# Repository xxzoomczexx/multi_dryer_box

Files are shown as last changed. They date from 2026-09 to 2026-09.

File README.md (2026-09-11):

# 🛠️ Multi-Box Filament Dryer - Hardware & 4-Layer PCB Design

Hardwarový návrh plošného spoje (PCB) pro řídicí desku sušičky filamentu s mikrokontrolérem **Raspberry Pi RP2350A** a Wi-Fi modulem **Raspberry Pi RM2**.

---

## 🎛️ 4-Vrstvý PCB Stackup (Maturitní Standard)

Návrh využívá **4vrstvou desku plošných spojů (4-Layer PCB)** pro zajištění vynikající elektromagnetické kompatibility (EMC), nízkého šumu pro 24-bitový ADC převodník váhy HX711 a stabilního chodu Wi-Fi modulu.

| Vrstva | Název v KiCad | Typ | Popis / Využití |
| :--- | :--- | :--- | :--- |
| **L1 (Top)** | `F.Cu` | **Signal** | Hlavní signálové vodiče (I2C, HX711, SWD, SPI pro Flash a RM2, spínání MOSFETu). |
| **L2 (Inner 1)** | `In1.Cu` | **GND Plane** | **Plná souvislá zemní plocha (GND)** pod všemi čipy, napájecím zdrojem i RF částí. |
| **L3 (Inner 2)** | `In2.Cu` | **Power Plane** | Rozlitá napájecí zóna (**+3.3V** a rozvod **+5V / +12V** pro topná tělesa). |
| **L4 (Bottom)**| `B.Cu` | **Signal / GND**| Propojovací signálové vodiče a spodní stínění zemí. |

---

## 🧩 Hlavní Hardwarové Bloky (Hierarchická Schémata)

- ⚡ **`pwr.kicad_sch` (Napájecí zdroj):** Spínaný DC-DC buck měnič **AP63203WU** (vstup 3.8 V až 32 V přes jack `PJ-102AH`, výstup **+3.3 V / 2 A** pro RP2350, Flash i RM2).
- 📡 **`RM2.kicad_sch` (Wi-Fi / BT modul):** Modul **Raspberry Pi RM2** (čip CYW43439) připojený přes rozhraní SPI.
- 💾 **`flash.kicad_sch` (Flash paměť):** 16 MB QSPI Flash paměť **W25Q128JVS** pro uložení firmwaru.
- 🔌 **`susicka_filamentu.kicad_sch` (Mikrokontrolér a konektory):**
  - **Čip:** RP2350A (QFN-60).
  - **Programování:** **SWD Konektor** (`J2` - 3-pin / 4-pin Header: `SWCLK`, `SWDIO`, `GND`, `+3V3`). *(USB větev je vynechána - DNP)*.
  - **I2C Senzor teploty a vlhkosti:** Rozhraní pro senzor SHT40 (`SDA`, `SCL` s 4.7kΩ pull-up rezistory).
  - **Tenzometr váhy (HX711):** 4-pin konektor pro HX711 (`VCC`, `SCK`, `DT`, `GND`).
  - **MOSFET Spínač topení:** N-kanálový MOSFET (**AO3400A** / **IRLML6344TRPBF** v pouzdře SOT-23) s 10kΩ pulldown rezistorem na gate a ochrannou flyback diodou.

---

## 📏 Návod pro Layout a DRC v KiCad

1. **Keepout zóna pro Wi-Fi anténu:** Pod anténní částí modulu RM2 odstraňte měděné zóny ze všech 4 vrstev pro zachování plného dosahu Wi-Fi.
2. **GND Vrstva (In1.Cu):** Narušovat souvislou zemní plochu L2 co nejméně. Všechny piny GND připojovat krátkými prokovy (vias) přímo na L2.
3. **Filtrační kondenzátory:** Blokovací kondenzátory 100 nF a 10 µF umístit těsně k napájecím pinům RP2350A, W25Q128, AP63203 i RM2.

---

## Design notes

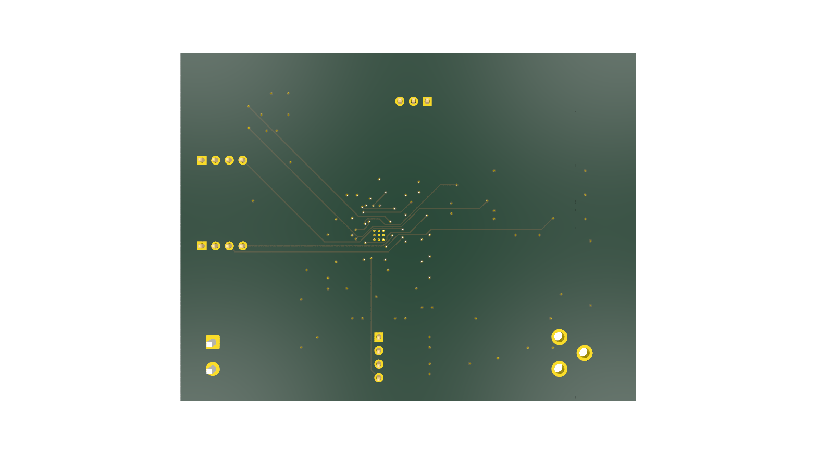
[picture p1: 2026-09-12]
pcb_bottom_render.png

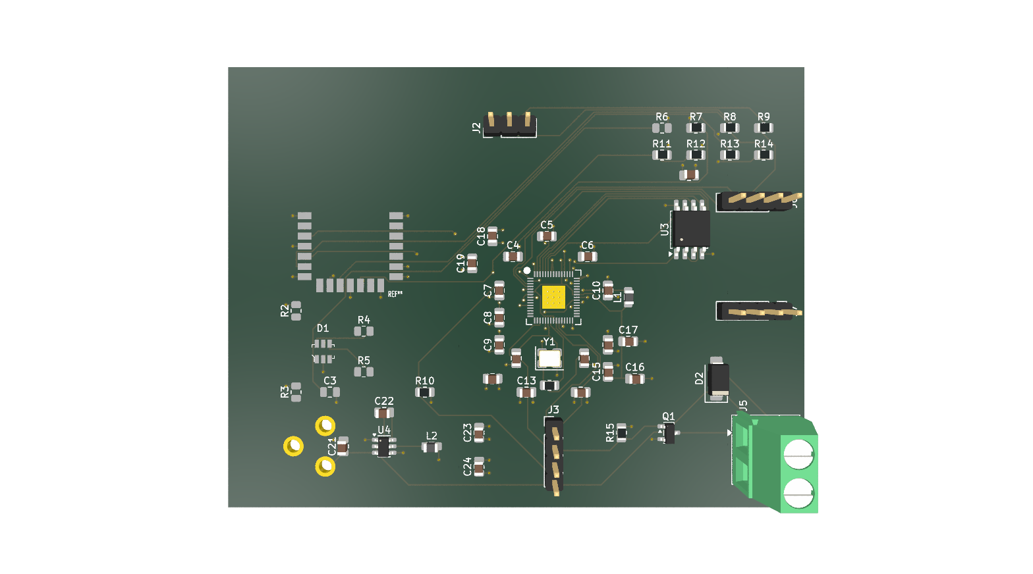
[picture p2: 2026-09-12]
pcb_top_render.png

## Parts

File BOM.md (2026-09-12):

# Kusovník součástek (Bill of Materials – BOM)
**Projekt:** IoT Sušička filamentu (*Maturitní práce*)  
**Deska:** 4vrstvá DPS (85 × 65 mm)  
**Datum:** 12. 9. 2026  

Tento kusovník obsahuje kompletní seznam všech součástek osazených na desce plošných spojů, včetně přesných katalogových čísel a odkazů z tabulky `C:\Users\mirac\Desktop\soucastky.xlsx`.

---

## 1. Souhrnná nákupní tabulka (Sdruženo podle typu součástky)

| Označení | Hodnota / Typ | Pouzdro | Počet | Reference na desce | Výrobce / Objednací kód | Odkaz na nákup |
| :--- | :--- | :--- | :---: | :--- | :--- | :--- |
| **U1** | **RP2350A** (MCU Dual ARM/RISC-V) | QFN-60 (7×7 mm, pitch 0,4 mm) | 1 ks | `U1` | Raspberry Pi `RP2350A0A4` | [TME](https://www.tme.eu/cz/details/sc1509-a4/raspberry-pi-vestavene-systemy/raspberry-pi/raspberry-pi-rp2350a0a4-7-reel/) |
| **U2** | **RM2** (Wi-Fi 4 / BLE 5.2 modul) | LGA / Castellated | 1 ks | `U2` | Raspberry Pi `RPI-RMC20452T` | [RPiShop](https://rpishop.cz/602192/raspberry-pi-radio-module-rmc20452t/) |
| **U3** | **W25Q128JVS** (128 Mbit QSPI Flash) | SOIC-8 (208 mil, 5,3×5,3 mm) | 1 ks | `U3` | Winbond `W25Q128JVSIQ-TR` | [Mouser](https://cz.mouser.com/ProductDetail/Winbond/W25Q128JVSIQ-TR?qs=qSfuJ%252Bfl%2Fd7vTyLA9kNdGw%3D%3D) |
| **U4** | **AP63203WU-7** (Step-down 24V $\to$ 3,3V 2A) | TSOT-23-6 | 1 ks | `U4` | Diodes Inc `AP63203WU-7` | [Mouser](https://cz.mouser.com/ProductDetail/Diodes-Incorporated/AP63203WU-7?qs=u16ybLDytRZ1JqxbuLkMJw%3D%3D) |
| **Y1** | **ABM8-272-T3** (Krystal 12.000 MHz) | SMD 3225-4Pin (3,2×2,5 mm) | 1 ks | `Y1` | Abracon `ABM8-272-T3` | [TME](https://www.tme.eu/cz/details/abm8-272-t3/resonators-and-generators/abracon/) |
| **L1** | **3,3 $\mu$H** (Power Inductor, VREG Core) | SMD 2016 / 0805 | 1 ks | `L1` | Abracon `AOTA-B201610S3R3-101-T` | [TME](https://www.tme.eu/cz/details/aota-b201610s3r3-1/tlumivky/abracon/aota-b201610s3r3-101-t/) |
| **L2** | **3,9 $\mu$H** (Power Inductor, Buck 3.3V) | SMD 2016 / 0805 | 1 ks | `L2` | Würth / Bourns (proud $\ge 2\text{ A}$) | Běžný SMD induktor |
| **Q1** | **N-MOSFET** (Spínač topení, 30V $\ge 5\text{A}$) | SOT-23 | 1 ks | `Q1` | např. `AO3400A` nebo `Si2302DS` | Běžný N-FET logická úroveň |
| **D1** | **USBLC6-2SC6** (ESD ochrana USB) | SOT-23-6 | 1 ks | `D1` | STMicroelectronics `USBLC6-2SC6` | TME / Mouser |
| **D2** | **SS14** (Schottky dioda 40V 1A) | SMA (DO-214AC) | 1 ks | `D2` | Běžná Schottky dioda `SS14` | TME / Mouser |
| **J4** | **PJ-102AH** (DC Jack 2,1×5,5 mm, 5A) | THT | 1 ks | `J4` | Same Sky (CUI) `PJ-102AH` | [Mouser](https://cz.mouser.com/ProductDetail/Same-Sky/PJ-102AH?qs=WyjlAZoYn50Yq4CrVLCXLw%3D%3D) |
| **J5** | **MKDS 1,5/ 2-5,00** (Šroubová svorkovnice 2p) | THT, rozteč 5,00 mm | 1 ks | `J5` | Phoenix Contact `1715721` | TME / Mouser |
| **J2** | **PinHeader 1×03** (Rozteč 2,54 mm) | THT Vertical | 1 ks | `J2` | Lámací kolíková lišta 2,54 mm | Běžná lišta |
| **J3, J6, J7** | **PinHeader 1×04** (Rozteč 2,54 mm / JST-XH) | THT Vertical | 3 ks | `J3, J6, J7` | Lámací kolíková lišta / JST-XH | Běžná lišta |

---

## 2. Pasivní součástky (Kondenzátory SMD 0805)

| Hodnota | Dielektrikum / Napětí | Počet | Označení na desce | Funkce v zapojení |
| :--- | :--- | :---: | :--- | :--- |
| **15 pF** | C0G/NP0, 50V | 2 ks | `C1, C2` | Zátěžové kondenzátory 12MHz krystalu Y1 |
| **4,7 nF** | X7R, 50V | 1 ks | `C3` | Vysokofrekvenční filtr na vstupu napájení USB |
| **100 nF** ($0{,}1\,\mu\text{F}$) | X7R, 25V / 50V | 13 ks | `C7, C8, C9, C10, C11, C12, C13, C14, C15, C17, C18, C20, C22` | Blokování VDD/IO pinů MCU, Flashky, RM2 a Bootstrap pro U4 |
| **4,7 $\mu$F** | X5R/X7R, 10V / 16V | 4 ks | `C4, C5, C6, C16` | Filtrace VREG_AVDD, Core 1.1V a lokální zásoba 3.3V |
| **10 $\mu$F** | X5R/X7R, 35V / 50V | 2 ks | `C19, C21` | Vstupní filtrace 24V u měniče U4 (`C21`) a filtrace RM2 (`C19`) |
| **22 $\mu$F** | X5R/X7R, 10V / 16V | 2 ks | `C23, C24` | Výstupní filtrace 3,3V měniče AP63203 |

*Celkem kondenzátorů:* **24 ks** (všechny v pouzdru SMD 0805 / 2012Metric).

---

## 3. Pasivní součástky (Rezistory SMD 0805)

| Hodnota | Tolerance | Počet | Označení na desce | Funkce v zapojení |
| :--- | :--- | :---: | :--- | :--- |
| **27 $\Omega$** | 1 %, 0805 | 2 ks | `R4, R5` | Sériové zakončení diferenciálních linek USB D+ / D- |
| **33 $\Omega$** | 1 %, 0805 | 1 ks | `R7` | Filtrační odpor pro interní lineární regulátor (VREG_AVDD) |
| **220 $\Omega$** | 1 %, 0805 | 2 ks | `R8, R9` | Sériové tlumicí rezistory pro SPI signály modulu RM2 |
| **470 $\Omega$** | 1 %, 0805 | 1 ks | `R14` | Tlumení datové linky modulu RM2 |
| **1 k$\Omega$** | 1 %, 0805 | 1 ks | `R1` | Sériový tlumicí rezistor oscilátoru Y1 (XOUT) |
| **5,1 k$\Omega$** | 1 %, 0805 | 2 ks | `R2, R3` | Konfigurační pull-down rezistory USB-C (CC1 / CC2) |
| **10 k$\Omega$** | 1 %, 0805 | 4 ks | `R10, R11, R12, R13` | Pull-up pro RUN/Reset tlačítko a řídicí linky RM2 |
| **100 k$\Omega$** | 5 %, 0805 | 1 ks | `R15` | Pull-down Gate rezistor pro MOSFET topení Q1 |
| **1 M$\Omega$** | 5 %, 0805 | 1 ks | `R6` | Paralelní zpětnovazební rezistor krystalu Y1 |

*Celkem rezistorů:* **15 ks** (všechny v pouzdru SMD 0805 / 2012Metric).

---

## 4. Doporučení pro nákup

1. **Pasiva (odpory a kondenzátory):**
   * Všechny pasivní součástky jsou zvoleny v pouzdru **0805 (2012 metric)**, což je ideální kompromis – snadno se pájí ručně mikropájkou i pastou, nejsou miniaturní jako 0402 a jsou extrémně levné (stojí jednotky haléřů za kus).
   * Doporučuji koupit rovnou vzorkovou knížečku (SMD sample book 0805) na AliExpressu nebo LaskaKitu, kde máš všechny hodnoty pohromadě.
2. **Klíčové čipy (U1, U2, U3, U4):**
   * Čipy RP2350A, W25Q128 a AP63203 objednej z Mouseru nebo TME podle přímých odkazů z tabulky.
   * Modul RM2 má skladem český RPiShop.cz.

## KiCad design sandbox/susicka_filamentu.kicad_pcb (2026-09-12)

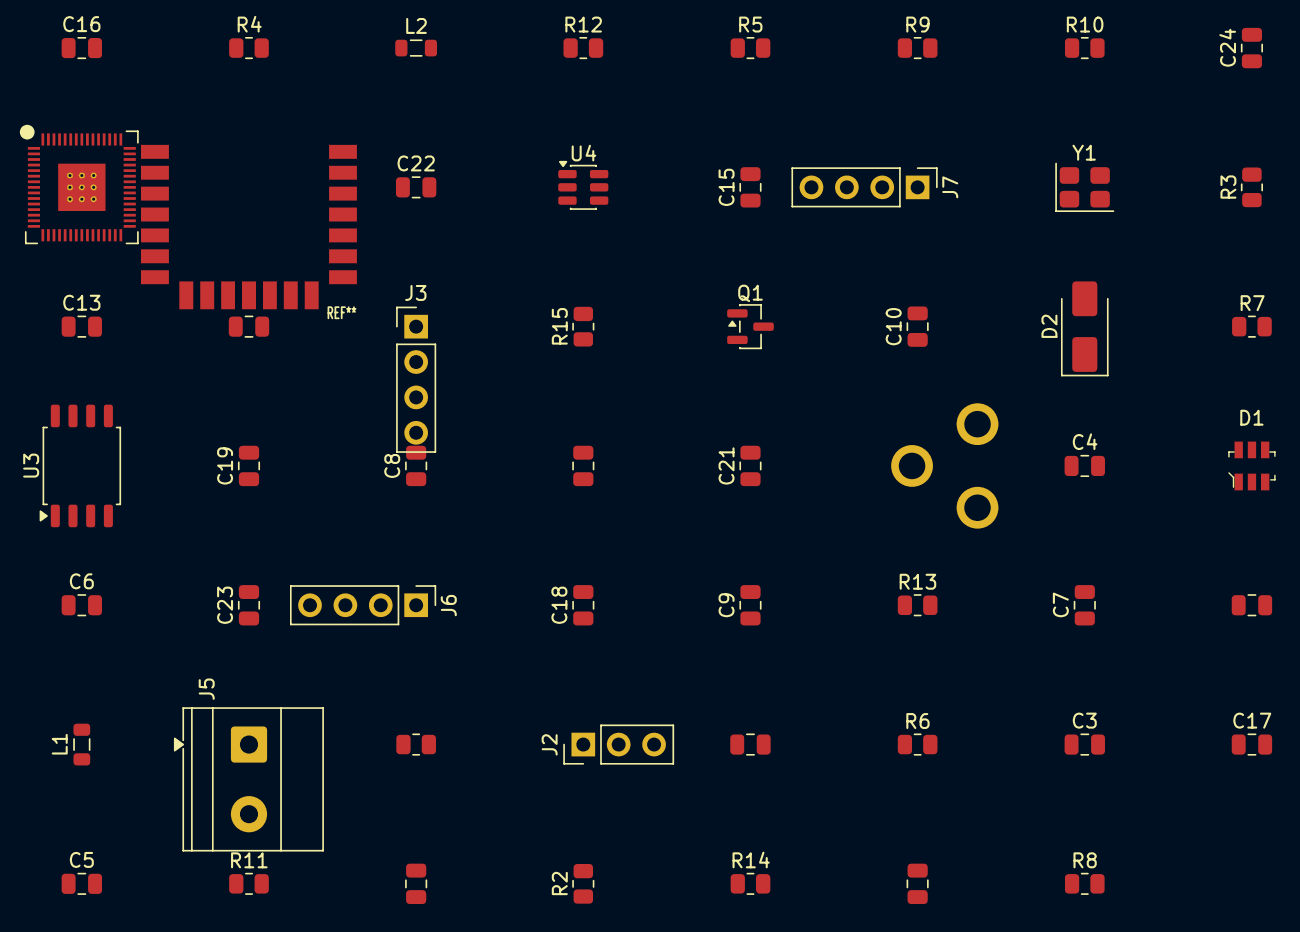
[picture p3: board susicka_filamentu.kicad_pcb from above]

Board: 4 copper layers, 55 parts (0 on the bottom side), 39 nets, no tracks yet.

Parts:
C1, C2: 15p; C_0805_2012Metric
C3: 4,7n; C_0805_2012Metric
C4: 4,7uF; C_0805_2012Metric
C5, C6, C16: 4,7 uF; C_0805_2012Metric
C7, C8, C9, C10, C11, C12, C13, C14, C15, C17, C18, C20, C22: 100 nF; C_0805_2012Metric
C19, C21: 10 uF; C_0805_2012Metric
C23, C24: 22 uF; C_0805_2012Metric
D1: USBLC6-2SC6; SOT23-6L
D2: SS14; D_SMA
J2: Conn_01x03; PinHeader_1x03_P2.54mm_Vertical
J3, J6, J7: Conn_01x04; PinHeader_1x04_P2.54mm_Vertical
J4: PJ-102AH
J5: Screw_Terminal_01x02; TerminalBlock_Phoenix_MKDS-1,5-2_1x02_P5.00mm_Horizontal
L1: AOTA-B201610S3R3-101-T; L_0805_2012Metric
L2: 3,9 uH; L_0805_2012Metric
Q1: Q_NMOS_GSD; SOT-23
R1: 1k; R_0805_2012Metric
R2, R3: 5,1k; R_0805_2012Metric
R4, R5: 27; R_0805_2012Metric
R6: 1M; R_0805_2012Metric
R7: 33; R_0805_2012Metric
R8, R9: 220; R_0805_2012Metric
R10, R11, R12, R13: 10k; R_0805_2012Metric
R14: 470; R_0805_2012Metric
R15: R; R_0805_2012Metric
U1: RP2350A-QFN60; RP2350A_QFN-60_EP_7.75x7.75_Pitch0.4mm
U2: RM2; rpi_rmc20452t
U3: W25Q128JVS; SOIC-8_5.3x5.3mm_P1.27mm
U4: AP63203WU; TSOT-23-6
Y1: Crystal_GND24; Crystal_SMD_3225-4Pin_3.2x2.5mm

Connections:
24V: C21.1, D2.1, J4.1, J5.1, U4.2 (EN), U4.3 (IN)
+1V1: C5.1, C15.1, C16.1, C17.1, L1.1, U1.6 (DVDD), U1.23 (DVDD), U1.39 (DVDD), U1.50 (VREG_FB)
+3V3: C6.1, C8.1, C9.1, C10.1, C11.1, C12.1, C13.1, C14.1, C18.1, C19.1, C20.1, C23.1, C24.1, J6.1, L2.2, R7.1, R10.2, U1.1 (IOVDD), U1.11 (IOVDD), U1.20 (IOVDD), U1.30 (IOVDD), U1.38 (IOVDD), U1.44 (ADC_AVDD), U1.45 (IOVDD), U1.49 (VREG_VIN), U1.53 (USB_OTP_VDD), U1.54 (QSPI_IOVDD), U2.14 (VDDIO), U2.16 (VIN), U3.8 (VCC), U4.1 (FB)
/GPIO14: Q1.1 (G), R15.1, U1.18 (GPIO14)
/RM2/RM2_BT_ON: R11.1, R12.1, U1.35 (GPIO23), U2.12 (WL_ON), U2.13 (BT_ON)
/RM2/RM2_CS: U1.37 (GPIO25), U2.9 (CS)
/RM2/RM2_DI: R13.1, R14.1, U1.36 (GPIO24), U2.5 (DI)
/RM2/RM2_SCLK: U1.43 (GPIO29_ADC3), U2.3 (SCLK)
/flash/QSPI_SCLK: U1.56 (QSPI_SCLK), U3.6 (CLK)
/flash/QSPI_SD0: U1.57 (QSPI_SD0), U3.5 (DI/IO_{0})
/flash/QSPI_SD1: U1.59 (QSPI_SD1), U3.2 (DO/IO_{1})
/flash/QSPI_SD2: U1.58 (QSPI_SD2), U3.3 (~WP/IO_{2})
/flash/QSPI_SD3: U1.55 (QSPI_SD3), U3.7 (~HOLD/~RESET/IO_{3})
/flash/QSPI_SS: U1.60 (QSPI_SS), U3.1 (~CS)
/oscillator/XIN: C1.2, U1.21 (XIN), Y1.3
/oscillator/XOUT: R1.2, U1.22 (XOUT)
DM: D1.4, R5.2
DP: D1.6, R4.2
GND: C1.1, C2.1, C3.2, C4.2, C5.2, C6.2, C7.1, C8.2, C9.2, C10.2, C11.2, C12.2, C13.2, C14.2, C15.2, C16.2, C17.2, C18.2, C19.2, C20.2, C21.2, C23.2, C24.2, D1.2, J2.3, J3.3, J4.2, J4.3, J6.2, J7.1, Q1.2 (S), R2.2, R3.2, R6.2, R11.2, R12.2, R15.2, U1.47 (VREG_PGND), U1.61 (GND), U2.1 (GND), U2.4 (GND), U2.7 (GND), U2.11 (GND), U2.15 (GND), U2.21 (GND), U3.4 (GND), U4.4 (GND), Y1.2, Y1.4
unnamed: C2.2, R1.1, Y1.1
unnamed: C3.1, R6.1
unnamed: J2.1, R8.2
unnamed: J2.2, R9.2
unnamed: C7.2, J3.4, R10.1, U1.26 (RUN)
unnamed: D2.2, J5.2, Q1.3 (D)
unnamed: J6.3, U1.4 (GPIO2)
unnamed: J6.4, U1.5 (GPIO3)
unnamed: J7.3, U1.7 (GPIO4)
unnamed: J7.4, U1.8 (GPIO5)
unnamed: R8.1, U1.2 (GPIO0)
unnamed: R9.1, U1.3 (GPIO1)
unnamed: C4.1, R7.2, U1.46 (VREG_AVDD)
unnamed: L1.2, U1.48 (VREG_LX)
unnamed: R14.2, U2.6 (DO)
unnamed: R13.2, U2.10 (nIRQ)
unnamed: C22.2, U4.6 (BST)
unnamed: C22.1, L2.1, U4.5 (SW)
SWCLK: J3.2, U1.24 (SWCLK)
SWDIO: J3.1, U1.25 (SWDIO)

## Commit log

2026-09-09 Prvotni import PCB
    [RM2.kicad_sch, flash.kicad_sch, pwr.kicad_sch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]
2026-09-11 Document 4-layer PCB stackup, SWD pinout, sensor headers and MOSFET heater switch
2026-09-11 Add KiCad schematic symbols for SHT40 header (J5), HX711 header (J6), MOSFET heater switch (Q1), and heater terminal (J7)
    [susicka_filamentu.kicad_sch]
2026-09-11 fix(pcb): repair KiCad 9 lib_symbols definitions and instances for SHT40, HX711, MOSFET Q1, and Heater J7
    [susicka_filamentu.kicad_sch]
2026-09-11 fix(pcb): fix syntax error on line 9044 (embedded_fonts no)
    [susicka_filamentu.kicad_sch]
2026-09-11 revert(pcb): restore original clean schematic file to prevent KiCad crash
    [susicka_filamentu.kicad_sch]
2026-09-11 clean(pcb): remove firmware files from PCB branch
2026-09-11 feat(pcb): verify schematic components and assign KiCad 9 footprints for J5, J6, J7, Q1, R15, D2
    [susicka_filamentu.kicad_sch]
2026-09-11 feat(pcb): add net labels (GPIO2, GPIO3, GPIO4, GPIO5, GPIO14, 3V3, GND, 12V) for sensors, MOSFET, and heater
    [susicka_filamentu.kicad_sch]
2026-09-11 fix(pcb): populate footprints for C1..C24, R1..R14, J1, J3, L1, L2, Y1 across all schematic sheets to eliminate import errors
    [RM2.kicad_sch, flash.kicad_sch, pwr.kicad_sch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]
2026-09-11 feat(pcb): assign exact footprints to all components across all schematic sheets matching BOM soucastky.xlsx
    [RM2.kicad_sch, flash.kicad_sch, pwr.kicad_sch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]
2026-09-11 feat(pcb): 4-layer stackup configuration, floorplan placement of RP2350A, RM2, sensors, MOSFET heater control, 85x65mm Edge.Cuts, and +3.3V/GND copper planes
    [susicka_filamentu.kicad_pcb]
2026-09-11 feat(pcb): Senior PCB Layout & Routing: enforce RF antenna Keepout zone, place MCU & decoupling caps adjacent to VDD, route power/GND vias, and generate +3V3/GND copper planes
    [susicka_filamentu.kicad_pcb]
2026-09-12 Complete senior 4-layer PCB layout & routing with 0 DRC errors and full keepout enforcement
    [susicka_filamentu.kicad_pcb, susicka_filamentu.kicad_sch]
2026-09-12 fix(pcb): finalize 4-layer routing with 0 DRC violations and add 3D renders
    [susicka_filamentu.kicad_pcb]
2026-09-12 feat(sandbox): add unrouted sandbox subfolder with clean and unrouted boards for practice
    [RM2.kicad_sch, flash.kicad_sch, pwr.kicad_sch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]
2026-09-12 docs: add complete Bill of Materials (BOM) cross-referenced with soucastky.xlsx
2026-09-12 Update passive component footprints to 0603 and sync DRC rules
    [RM2.kicad_sch, flash.kicad_sch, pwr.kicad_sch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]
2026-10-19 Remove secrets and KiCad local files from PCB branch
    - config.h with Wi-Fi credentials does not belong in the PCB branch
    - KiCad backups and .kicad_prl are local/generated, now ignored
2026-10-19 Replace Gemini-generated layout with clean project for manual layout
    Remove generated scripts, test boards, DRC reports, renders and build
    output; restore the sandbox project so the PCB layout can be done by hand.
2026-10-19 Ignore KiCad fp-info-cache
2026-10-19 Complete schematic for first prototype
    - Footprints: passives 0402/0603 (larger only for 24 V / DC bias),
    U1 and L1 footprints taken from RP2350A Minimal R4 reference (MIT)
    - New sheet vystupy: heater (Q1 SiS434DN) with thermal fuse terminal J13,
    fan (GPIO13) and exhaust fan (GPIO12) with AO3422, input protection
    (fuse, AOD4185 reverse polarity, SMBJ24CA TVS, bulk cap), status LED on
    RM2 GPIO0, button GPIO15, NTC on ADC0 (22k pull-up), I2C1 pull-ups,
    second SHT40 on I2C0 (GPIO8/9)
    - New sheet rozsireni: spare GPIO header J12, test points TP1-TP5,
    mounting holes H1-H4
    - Selected parts with Manufacturer/MPN fields; L2 4.7 uH Wurth 74438356047
    - Fix D2 pin mapping (Device:D_Schottky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
2026-10-19 Add communication test points, tidy root sheet, board setup
    - Test points TP6-TP19 (1 mm pads) on I2C1, I2C0, HX711, RM2 gSPI,
    heater/fan/exhaust PWM and NTC ADC, plus TP12 GND loop
    - Root sheet: GPIO2-5 -> J6/J7 and GPIO24/25/29 -> RM2 now connected by
    global labels (HX711_DT/SCK, WL_DATA/CS/CLK), J6 moved
    - Board updated from schematic (F8)
    - Board setup: min through-hole 0.2 mm (0.25 mm vias under RP2350),
    new net class Power (1.5 mm track, 0.3 mm clearance, 0.8/0.4 via)
    for 24V_IN, 24V, fuse/heater nets
2026-10-19 Layout progress, VREG per reference, SI simulation, project notes
    - Board: 70x100 mm outline, mounting holes, crystal, RP2350 decoupling,
    VREG copied from RP2350A Minimal R4 (zones, priorities, PGND track),
    RM2 placement and gSPI routing (CLK 16.5 mm, DATA 14.4 mm),
    RF keep-out rule area on all copper layers, test points TP12-TP15
    - C4/C5/C6/R7 in 0402; C5/C6 use susicka:C_0402_1005Metric_RPi
    (0.56 mm pad gap so VREG_LX passes under the caps)
    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
2026-10-19 Place and route RP2350 decoupling capacitors
    - C11 (pin 30), C13 (pins 44+45), C14 (pins 53+54) next to their pins
    - C12 for pin 38 via +3V3 plane: pin 38 has a via under the package,
    C12 above C13 with its own +3V3 via and shared GND via
    - C9/C16/C17/C8/C10/C15 kept; zones refilled (fixes GND via vs +1V1 zone clearance)
2026-10-20 Update PCB layout (current working version)
2026-10-21 Layout: I2C pull-ups, test point properties, power section progress
    - R21/R22 (I2C1) and R26/R27 (I2C0) placed and routed
    - test point fabrication property on placed TPs
    - J6 SDA/SCL order swapped in schematic for routing
    - J1 (USB, DNP) excluded from board
2026-10-26 Layout review fixes and JLCPCB fabrication outputs
    - In2: GND pour over the whole board (priority 0) below the 3V3 zones
    - Silkscreen: +/- marks of J5, J8, J9 moved out from under the terminal
    blocks; D4 and TP13 labels moved to visible spots
    - TP12 moved away from the RM2 antenna keep-out, J4 shifted up,
    R20 220R so the D6 LED is visible at 3.3 V
    - NTC (J10, R25, C26, TP19) excluded from this prototype board
    - gerber/: fresh Gerber + Excellon export, JLCPCB zip, ordering notes
    - CLAUDE.md, .claude/pamet.md: review results and decisions
2026-10-26 Add component shopping list (BOM) with current values
    - jlcpcb/BOM_JLCPCB.csv: R20 moved to 220R (RC0603FR-07220RL),
    C5/C6 listed with their RPi 0402 footprint, J4 PJ-102AH added
    - Cross-checked against the schematic: 64 parts, footprints match
    - CLAUDE.md: note what the BOM contains
2026-10-26 BOM: add terminal blocks, pin headers and GND test loops
    - J5, J8, J9, J13: Phoenix 1715022 (MKDS 1,5/2, 5.0 mm pitch to match
    the footprint; 1715721 is the 5.08 mm variant)
    - J2 / J3, J6, J7, J11 / J12: Würth WR-PHD 61300311121 / 61300411121 /
    61301421121
    - TP4, TP5, TP12: Keystone 5001 (1.0 mm hole)
2026-10-26 BOM: add quantities and Mouser/TME search links
    Each line now has the per-board quantity and search links by MPN.
    RP2350A and RM2 are searched by Raspberry Pi ordering terms
    (RP2350A, SC1169), which is how Mouser lists them.
2026-10-27 Order PCB and components: 0.3 mm holes, OSP, purchase lists
    - Enlarge 16 holes (7 VREG vias + 9 U1 thermal pad holes) from 0.25 to 0.3 mm
    to avoid JLCPCB surcharge; annular ring unchanged, DRC and zones unchanged
    - Regenerate gerbers (susicka_filamentu_JLCPCB_2026-10-27.zip), update order
    guide (OSP finish, 0.3 mm min via)
    - Add NAKUP.md shopping list, Mouser and TME import files
    - BOM: record purchased substitutes (same value and package)
2026-11-03 Note: Debug Probe owned, list remaining off-board purchases
